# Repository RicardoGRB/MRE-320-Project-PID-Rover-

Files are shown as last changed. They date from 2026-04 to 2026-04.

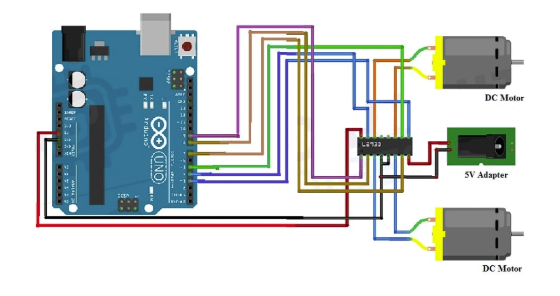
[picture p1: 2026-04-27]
Diagrams and Pictures/Wiring Diagrams/L293D&Motors_Diagram.png

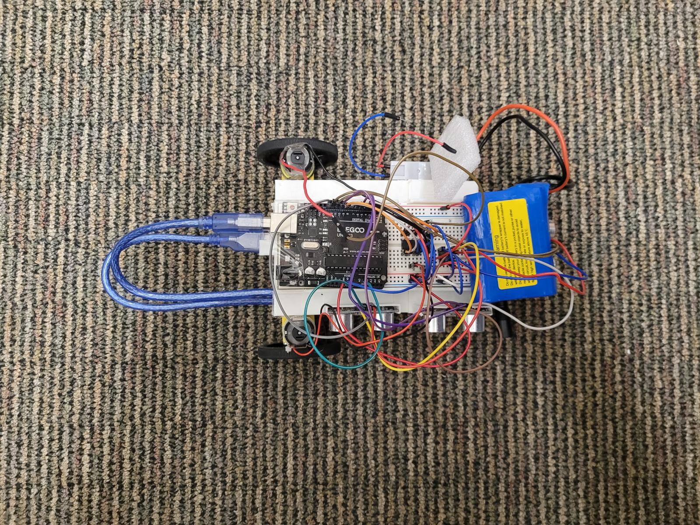
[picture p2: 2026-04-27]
Diagrams and Pictures/pictures/Rover above picture.jpeg

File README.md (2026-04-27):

# MRE-320-Project-PID-Rover-
# Autonomous Wall-Following Rover

## Overview

This project involves the design and implementation of an **autonomous mobile robot** capable of following a wall at a fixed distance using **feedback control**. The system uses ultrasonic sensors to measure distance and a **PID (Proportional–Integral–Derivative) controller** to continuously adjust the robot’s motion.

The project emphasizes the practical application of:

- Control systems (PID control)
- Sensor integration
- Embedded system design
- Mechanical design (custom chassis)

The rover was designed, built, and programmed to operate **fully autonomously**, maintaining a consistent distance from a wall while navigating alongside it.

---

## Project Goals

The main objectives of this project were:

- Design and build a **mobile robotic platform**
- Implement a **closed-loop control system** using a PID controller
- Maintain a **constant distance from a wall**
- Use **ultrasonic sensors** for real-time distance measurement
- Integrate hardware and software into a **fully autonomous system**
- Design and fabricate a **custom chassis** for the rover

---

## System Architecture

The rover system is composed of three main subsystems:

### 1. Sensing System

- Two **ultrasonic sensors** are mounted on the rover
- Sensors measure the **distance to the wall**
- Multiple sensors improve **stability and accuracy** of distance estimation

---

### 2. Control System

- A **PID controller** is implemented in the microcontroller
- The controller computes the error between:

  ```
  Error = Desired Distance − Measured Distance
  ```

- Based on this error, the controller adjusts motor behavior using:

  - **Proportional term (P):** reacts to current error  
  - **Integral term (I):** corrects accumulated error  
  - **Derivative term (D):** anticipates future error  

- The output of the PID controller is used to **adjust motor speeds** for steering correction

---

### 3. Actuation System

- The rover uses **two driven wheels** for propulsion
- A **passive omniwheel** is mounted at the front of the chassis
- The omniwheel allows **free lateral movement**, reducing friction during turns
- Steering is achieved through **differential drive**:
  - The robot turns by varying the speeds of the left and right motors
- This configuration enables **smooth directional corrections** while maintaining forward motion

---

### 4. Mechanical System

- A **custom chassis** was designed and built for the rover
- The chassis supports:
  - Sensor placement
  - Motor mounting
  - Electronics integration
  - Omniwheel placement for stability and maneuverability
- The design ensures:
  - Stability
  - Proper alignment with the wall
  - Reliable sensor readings

---

## Implementation Overview

### Sensor Integration

- Two ultrasonic sensors continuously measure the distance to the wall
- Sensor readings are processed in real time
- Data is used as input for the control algorithm

---

### Control Algorithm

1. Read distance from ultrasonic sensors  
2. Compute error relative to desired distance  
3. Apply PID control equation  
4. Generate correction signal  
5. Adjust motor speeds accordingly  

This loop runs continuously to ensure real-time response.

---

### Motor Control

- Motor speeds are adjusted based on PID output
- Differential drive is used to steer the rover
- The front omniwheel allows smooth turning without resistance
- Small speed adjustments result in precise wall-following behavior

---

### Chassis Design

- The rover chassis was **custom designed and built**
- Key considerations included:
  - Sensor positioning for accurate readings
  - Weight distribution
  - Structural stability
  - Integration of the omniwheel for improved maneuverability

---

## System Behavior

During operation, the rover:

1. Moves forward along a wall  
2. Continuously measures distance using ultrasonic sensors  
3. Computes error relative to the desired distance  
4. Adjusts its trajectory using PID control  
5. Maintains a stable and consistent path along the wall  

---

## Repository Structure

```
Autonomous-Wall-Following-Rover
│
├── README.md
│
├── code
│   └── rover_control
│
├── diagrams and Pictures
│   ├── chassis/solidworks
│   └── wiring_diagrams
│   └──pictures
│
├── data
│
├── engineering problem solving
│
└── final results

```

---

## Project Context

This project was completed as part of a **sensors and actuators assignment**, focusing on the integration of:

- Sensors  
- Control algorithms  
- Embedded programming  
- Mechanical design  

The project demonstrates a complete **mechatronic system**, combining hardware and software to achieve autonomous behavior.

---

---

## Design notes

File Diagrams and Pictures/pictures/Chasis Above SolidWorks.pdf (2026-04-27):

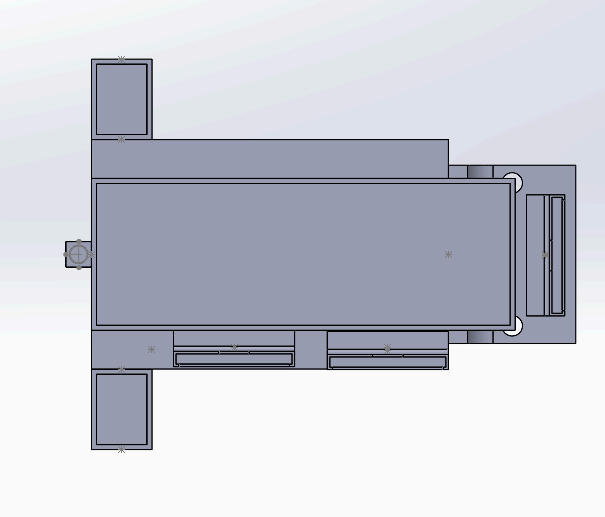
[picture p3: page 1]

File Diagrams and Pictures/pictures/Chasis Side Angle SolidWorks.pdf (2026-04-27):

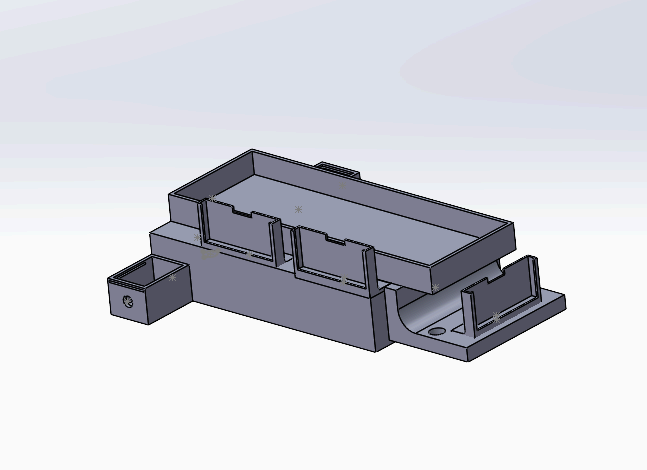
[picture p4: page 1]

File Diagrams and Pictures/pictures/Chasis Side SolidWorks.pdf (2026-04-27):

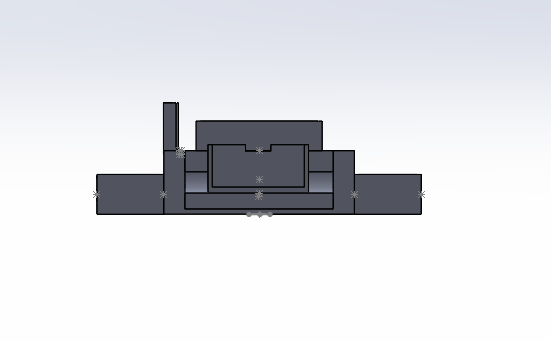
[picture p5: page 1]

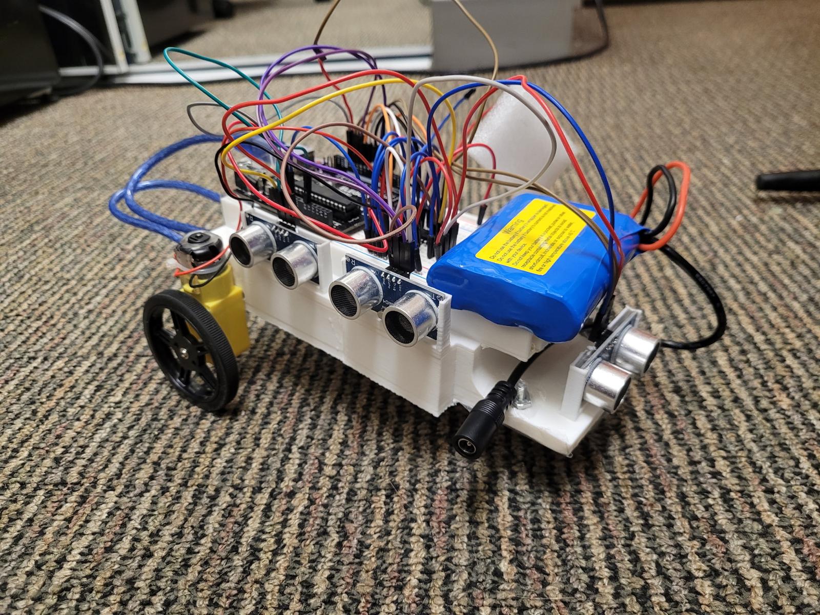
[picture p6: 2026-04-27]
Diagrams and Pictures/pictures/Rover side picture.jpeg

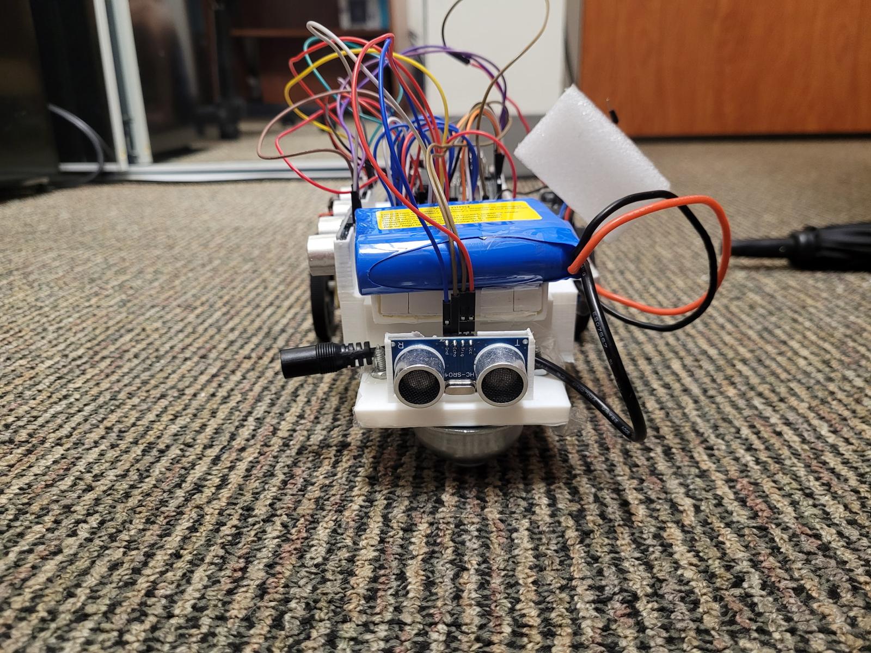
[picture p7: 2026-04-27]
Diagrams and Pictures/pictures/Rover Front picture.jpeg

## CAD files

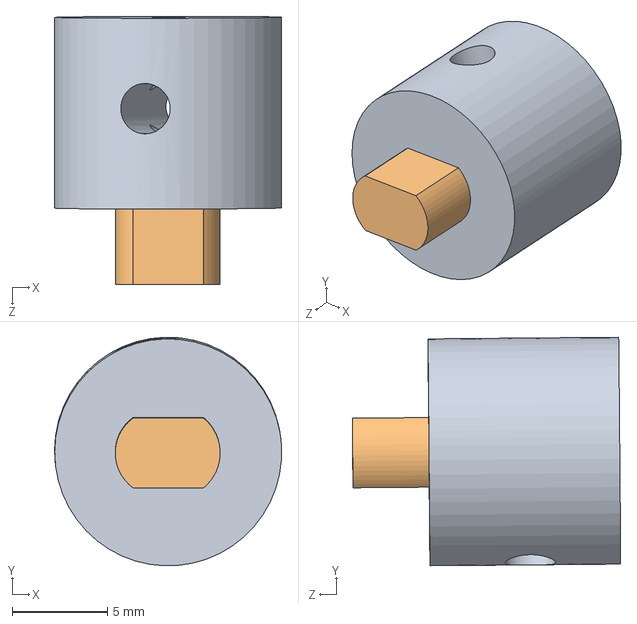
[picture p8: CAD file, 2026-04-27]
Diagrams and Pictures/Chasis/SolidWorksFiles/Motor assembly.SLDASM
11.9 x 12.0 x 14.1 mm
wheel hole
motor sheathe

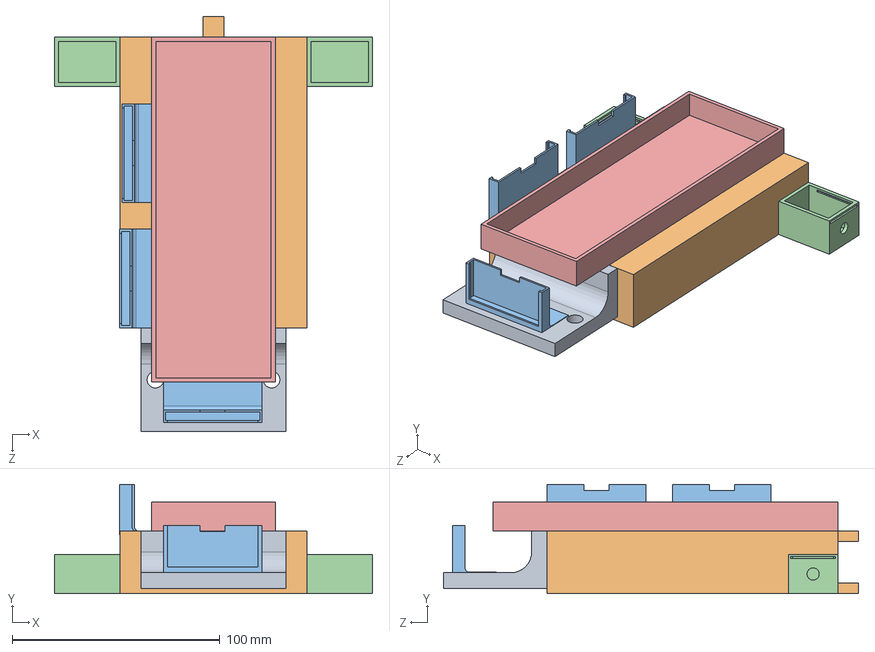
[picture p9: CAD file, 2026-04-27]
Diagrams and Pictures/Chasis/SolidWorksFiles/Final assembly.SLDASM
153.2 x 52.6 x 200.0 mm
bread board holder
motor box x 2
ultrasonic sensor plate x 3
Battery Case
RollerWheelMount

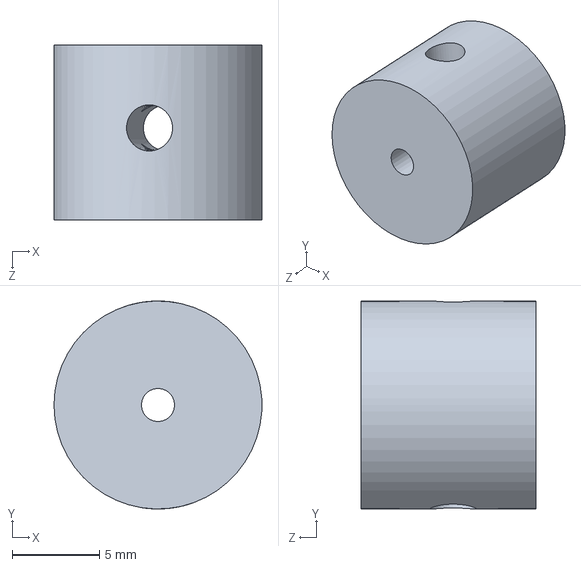
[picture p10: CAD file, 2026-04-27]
Diagrams and Pictures/Chasis/SolidWorksFiles/motor sheathe.SLDPRT
11.9 x 11.9 x 10.0 mm

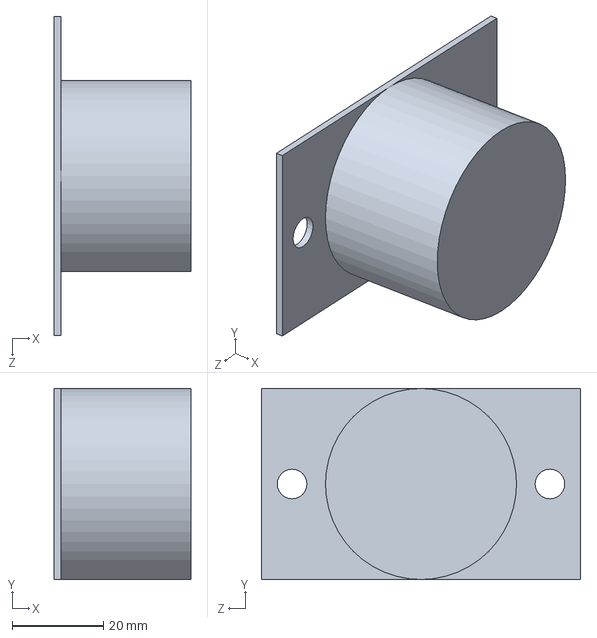
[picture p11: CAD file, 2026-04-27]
Diagrams and Pictures/Chasis/SolidWorksFiles/Front Wheel.SLDPRT
30.0 x 41.9 x 70.0 mm

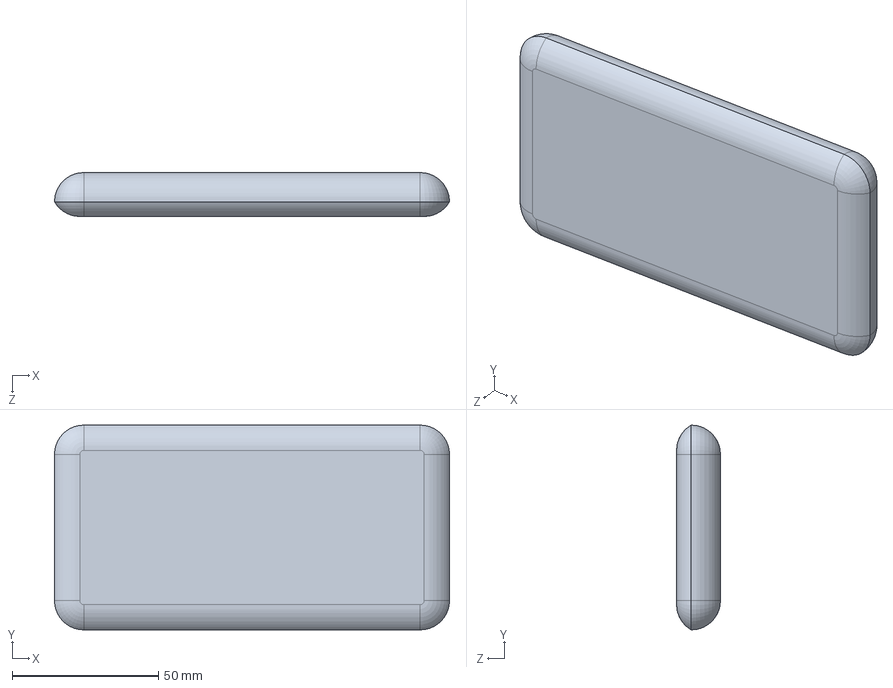
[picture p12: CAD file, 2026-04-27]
Diagrams and Pictures/Chasis/SolidWorksFiles/Battery.SLDPRT
135.0 x 70.0 x 15.0 mm

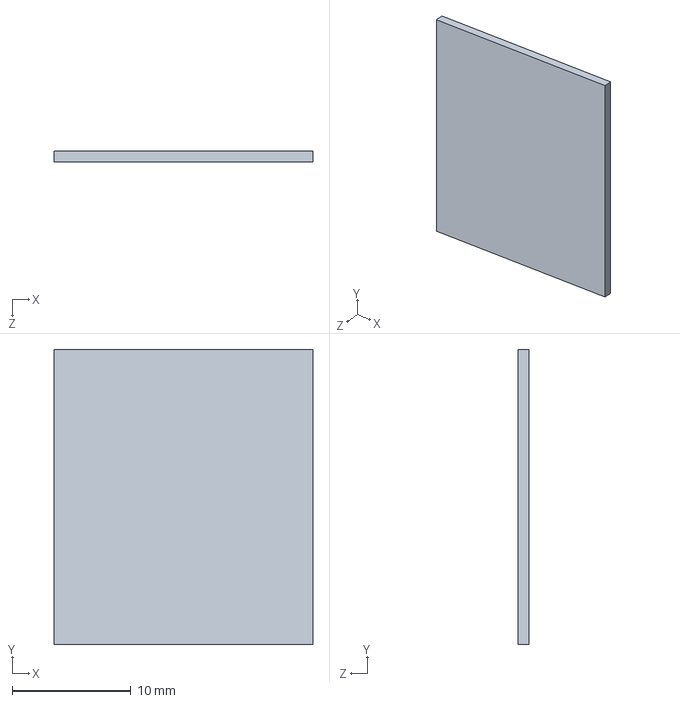
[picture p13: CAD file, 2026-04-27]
Diagrams and Pictures/Chasis/SolidWorksFiles/Motor box door.SLDPRT
21.7 x 24.8 x 0.95 mm

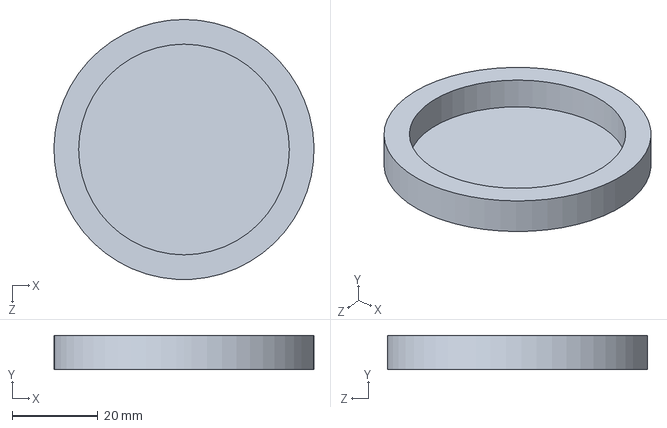
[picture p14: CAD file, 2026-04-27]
Diagrams and Pictures/Chasis/SolidWorksFiles/Rear Wheel.SLDPRT
60.5 x 8.00 x 60.5 mm

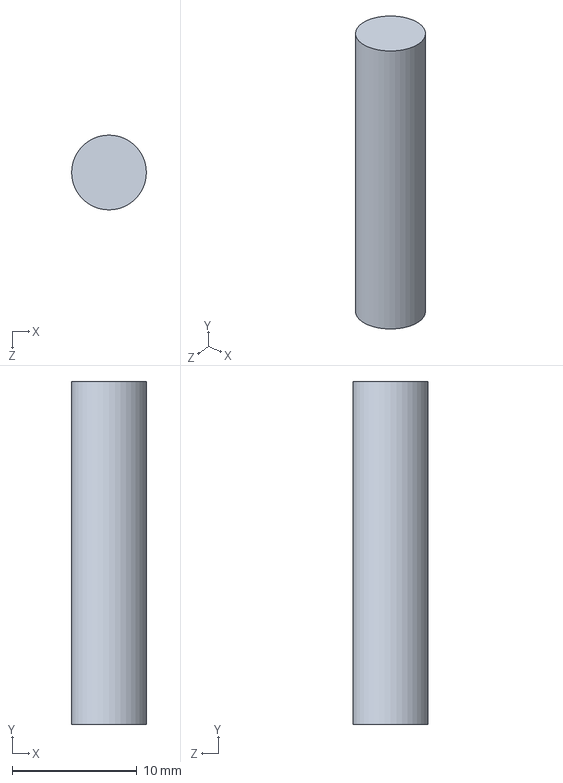
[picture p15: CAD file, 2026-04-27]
Diagrams and Pictures/Chasis/SolidWorksFiles/LockRod for Battery Case.SLDPRT
6.00 x 27.5 x 6.00 mm

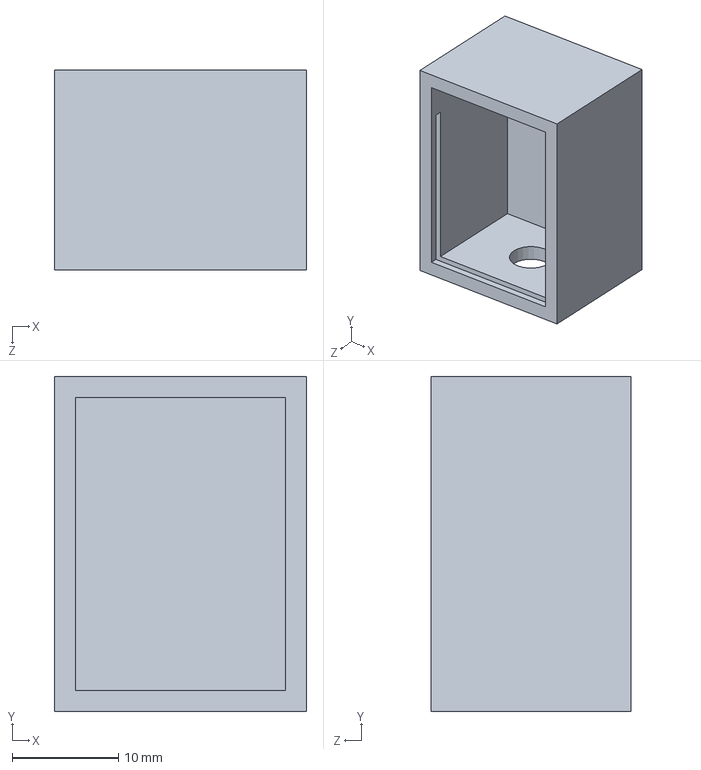
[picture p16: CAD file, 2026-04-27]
Diagrams and Pictures/Chasis/SolidWorksFiles/motor box.SLDPRT
23.8 x 31.6 x 18.9 mm

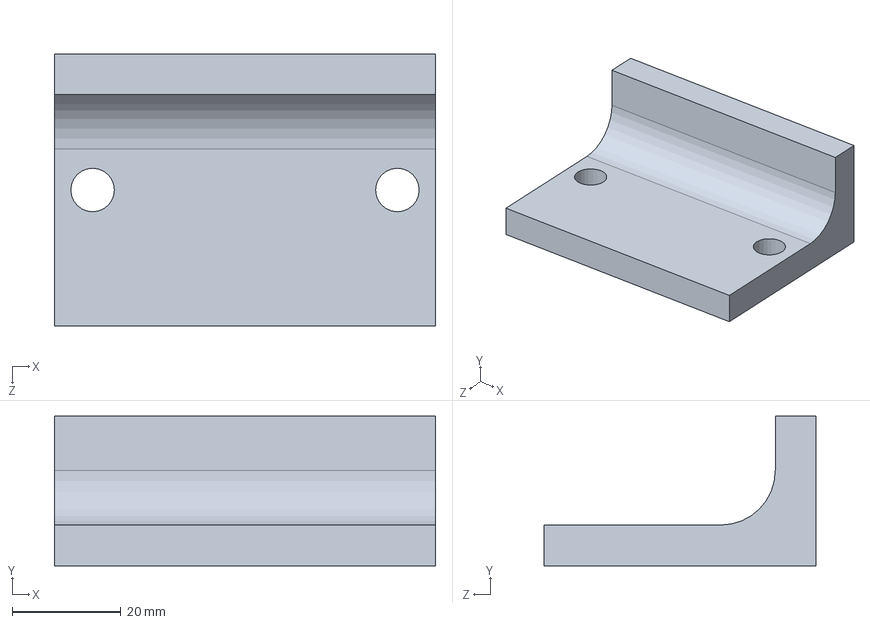
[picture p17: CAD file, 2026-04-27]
Diagrams and Pictures/Chasis/SolidWorksFiles/RollerWheelMount.SLDPRT
70.0 x 27.5 x 50.0 mm

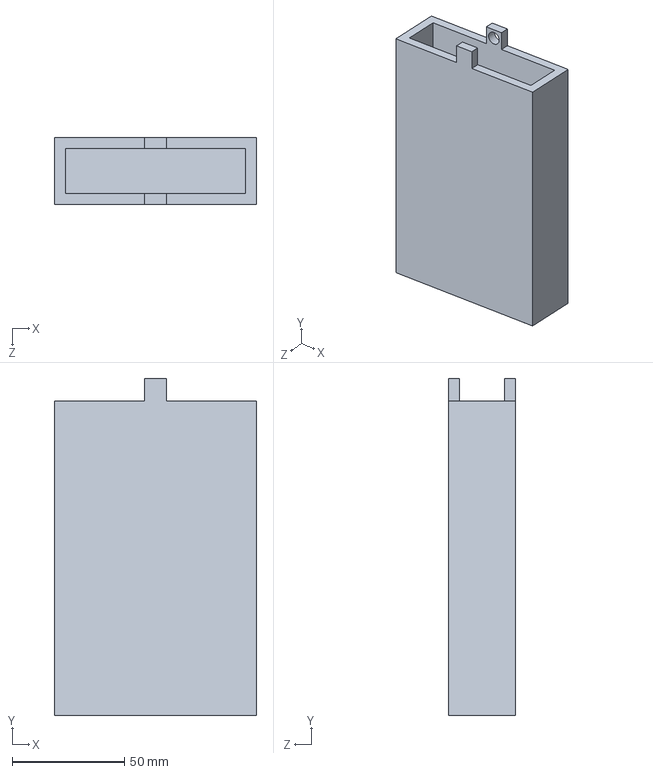
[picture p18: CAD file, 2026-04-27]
Diagrams and Pictures/Chasis/SolidWorksFiles/Battery Case.SLDPRT
90.0 x 150.0 x 30.0 mm

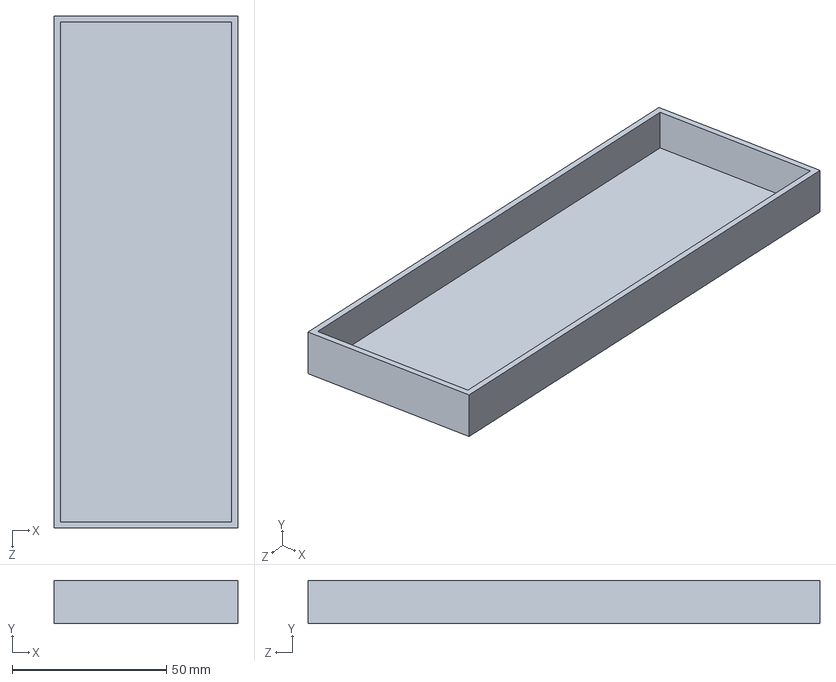
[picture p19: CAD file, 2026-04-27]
Diagrams and Pictures/Chasis/SolidWorksFiles/bread board holder.SLDPRT
59.6 x 14.0 x 166.2 mm

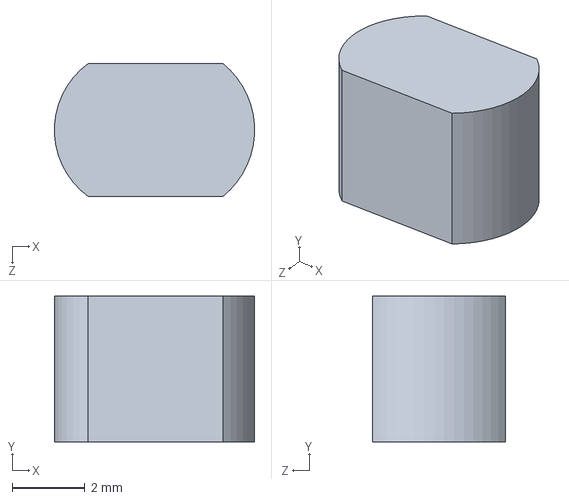
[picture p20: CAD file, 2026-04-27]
Diagrams and Pictures/Chasis/SolidWorksFiles/wheel hole.SLDPRT
5.49 x 4.00 x 3.65 mm

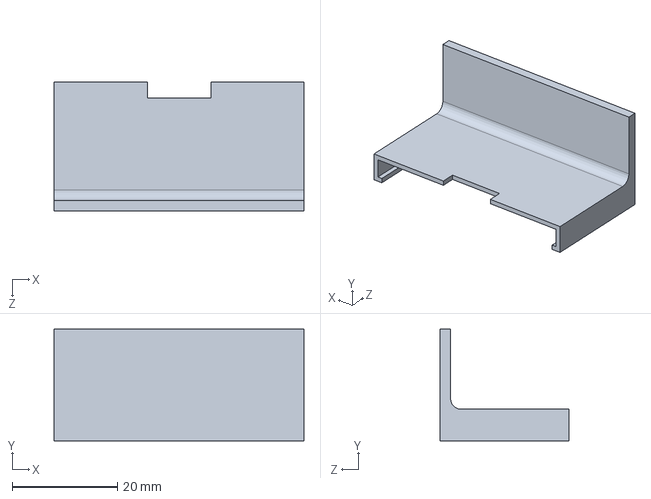
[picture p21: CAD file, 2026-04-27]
Diagrams and Pictures/Chasis/SolidWorksFiles/ultrasonic sensor plate.SLDPRT
47.5 x 21.2 x 24.5 mm

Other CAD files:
Diagrams and Pictures/Chasis/SolidWorksFiles/ultrasonic sensor mount.SLDPRT

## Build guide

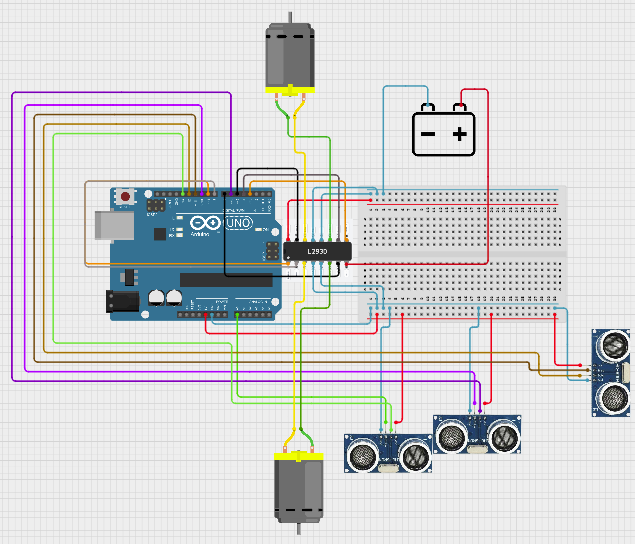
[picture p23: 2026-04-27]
Diagrams and Pictures/Wiring Diagrams/Master_Wiring_Diagram.png

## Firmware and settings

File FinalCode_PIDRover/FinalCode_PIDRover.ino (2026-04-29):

// ── Motor A (RIGHT WHEEL) ────────────────────────────────
const int ENA = 9;  const int IN1 = 8;  const int IN2 = 7;
// ── Motor B (LEFT WHEEL) ─────────────────────────────────
const int ENB = 3;  const int IN3 = 5;  const int IN4 = 4;
// ── Ultrasonic Sensors ───────────────────────────────────
const int TRIG_FRONT = 11; const int ECHO_FRONT = 12;
const int TRIG_SF    = 6;  const int ECHO_SF    = 10;  // Side-Front
const int TRIG_SR    = 13; const int ECHO_SR    = A0;  // Side-Rear

// ── Core Parameters ──────────────────────────────────────
const float TARGET_DIST     = 32.0;  // cm from wall
const float FRONT_STOP_DIST = 35.0;  // cm — stop threshold
const int   BASE_SPEED      = 90;    // 0–255 PWM base
const int   MAX_ADJUST      = 80;    // Max PID correction added/removed

// ── Motor Trim ───────────────────────────────────────────
// Boosting the weak left motor
const int LEFT_TRIM = 28;

// ── PID Gains ────────────────────────────────────────────
const float Kp = 1.5;
const float Ki = 0.05;
const float Kd = 2.5;

// ── Sensor Median Filter ─────────────────────────────────
const int FILTER_SIZE = 5;
long frontBuf[FILTER_SIZE], sfBuf[FILTER_SIZE], srBuf[FILTER_SIZE];
int  frontIdx = 0, sfIdx = 0, srIdx = 0;
bool frontFull = false, sfFull = false, srFull = false;

// ── PID State ────────────────────────────────────────────
float integral   = 0.0;
float lastError  = 0.0;
unsigned long lastTime = 0;

// ── Startup kick (one-time only) ─────────────────────────
bool started = false;

void setup() {
  pinMode(ENA, OUTPUT); pinMode(IN1, OUTPUT); pinMode(IN2, OUTPUT);
  pinMode(ENB, OUTPUT); pinMode(IN3, OUTPUT); pinMode(IN4, OUTPUT);
  pinMode(TRIG_FRONT, OUTPUT); pinMode(ECHO_FRONT, INPUT);
  pinMode(TRIG_SF,    OUTPUT); pinMode(ECHO_SF,    INPUT);
  pinMode(TRIG_SR,    OUTPUT); pinMode(ECHO_SR,    INPUT);

  for (int i = 0; i < FILTER_SIZE; i++) {
    frontBuf[i] = 100;
    sfBuf[i]    = TARGET_DIST;
    srBuf[i]    = TARGET_DIST;
  }

  Serial.begin(9600);
  Serial.println("PID Wall Follower Ready");
  Serial.print("LEFT_TRIM = "); Serial.println(LEFT_TRIM);
}

// ── Raw distance read. Returns -1 on timeout/invalid. ────
long readRaw(int trigPin, int echoPin) {
  digitalWrite(trigPin, LOW);
  delayMicroseconds(2);
  digitalWrite(trigPin, HIGH);
  delayMicroseconds(10);
  digitalWrite(trigPin, LOW);

  long duration = pulseIn(echoPin, HIGH, 25000);
  if (duration <= 0) return -1;
  long dist = duration * 0.034 / 2;
  if (dist < 1 || dist > 400) return -1;
  return dist;
}

// ── Push a valid reading into a circular buffer. ─────────
void pushReading(long val, long* buf, int &idx, bool &full) {
  if (val == -1) return;
  buf[idx] = val;
  idx = (idx + 1) % FILTER_SIZE;
  if (idx == 0) full = true;
}

// ── Compute median of a buffer. ──────────────────────────
long median(long* buf, bool full) {
  int n = full ? FILTER_SIZE : 1;
  long sorted[FILTER_SIZE];
  memcpy(sorted, buf, n * sizeof(long));
  for (int i = 1; i < n; i++) {
    long key = sorted[i];
    int j = i - 1;
    while (j >= 0 && sorted[j] > key) { sorted[j+1] = sorted[j]; j--; }
    sorted[j+1] = key;
  }
  return sorted[n / 2];
}

// ── Drive both motors forward. LEFT_TRIM applied here. ───
void setMotors(int leftSpeed, int rightSpeed) {
  // Boost the weaker left motor
  leftSpeed = leftSpeed + LEFT_TRIM;

  leftSpeed  = constrain(leftSpeed,  0, 255);
  rightSpeed = constrain(rightSpeed, 0, 255);

  digitalWrite(IN3, HIGH); digitalWrite(IN4, LOW);  // Left forward
  digitalWrite(IN1, HIGH); digitalWrite(IN2, LOW);  // Right forward
  analogWrite(ENB, leftSpeed);
  analogWrite(ENA, rightSpeed);
}

void stopMotors() {
  analogWrite(ENA, 0);
  analogWrite(ENB, 0);
  integral  = 0.0;
  lastError = 0.0;
  started   = false;
}

void loop() {
  // 1. Read sensors into buffers
  pushReading(readRaw(TRIG_FRONT, ECHO_FRONT), frontBuf, frontIdx, frontFull);
  delay(5);
  pushReading(readRaw(TRIG_SF, ECHO_SF),       sfBuf,    sfIdx,    sfFull);
  delay(5);
  pushReading(readRaw(TRIG_SR, ECHO_SR),       srBuf,    srIdx,    srFull);

  // 2. Get filtered distances
  long frontDist = median(frontBuf, frontFull);
  long sfDist    = median(sfBuf,    sfFull);
  long srDist    = median(srBuf,    srFull);

  Serial.print("F:"); Serial.print(frontDist);
  Serial.print(" SF:"); Serial.print(sfDist);
  Serial.print(" SR:"); Serial.println(srDist);

  // 3. Front obstacle check
  if (frontDist < FRONT_STOP_DIST) {
    stopMotors();
    Serial.println(">>> STOPPED: Front obstacle <<<");
    delay(200);
    return;
  }

  // 4. One-time startup kick to overcome static friction
  if (!started) {
    digitalWrite(IN3, HIGH); digitalWrite(IN4, LOW);
    digitalWrite(IN1, HIGH); digitalWrite(IN2, LOW);
    analogWrite(ENB, constrain(255 + LEFT_TRIM, 0, 255)); // Left kick with trim
    analogWrite(ENA, 255);                                 // Right kick
    delay(300);
    started = true;
    lastTime = millis();
  }

  // 5. Compute dt
  unsigned long now = millis();
  float dt = (now - lastTime) / 1000.0;
  if (dt <= 0) dt = 0.04;
  lastTime = now;

  // ── PID CONTROL ──────────────────────────────────────────
  float sideDist   = (sfDist + srDist) / 2.0;
  float distError  = sideDist - TARGET_DIST;
  float angleError = (float)(sfDist - srDist);
  float error      = distError + (angleError * 0.6);

  // P term
  float P = Kp * error;

  // I term (with windup clamp)
  integral += error * dt;
  integral = constrain(integral, -50.0, 50.0);
  float I = Ki * integral;

  // D term
  float D = Kd * ((error - lastError) / dt);
  lastError = error;

  float correction = P + I + D;
  correction = constrain(correction, -MAX_ADJUST, MAX_ADJUST);

  // Positive error = too far from wall → steer right → left faster, right slower
  int leftSpeed  = BASE_SPEED + (int)correction;
  int rightSpeed = BASE_SPEED - (int)correction;

  setMotors(leftSpeed, rightSpeed);

  Serial.print("err:"); Serial.print(error);
  Serial.print(" P:"); Serial.print(P);
  Serial.print(" I:"); Serial.print(I);
  Serial.print(" D:"); Serial.print(D);
  Serial.print(" L:"); Serial.print(leftSpeed + LEFT_TRIM); // Show actual PWM
  Serial.print(" R:"); Serial.println(rightSpeed);

  delay(40);
}

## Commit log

2026-04-27 Create Wiring Diagrams
2026-04-27 Create Ultrasonic Sensor
2026-04-27 Create Ultrasonic Sensor
2026-04-27 Create • Measured data and analysis
2026-04-27 Rename • Measured data and analysis to Measured data and analysis
2026-04-27 Update and rename • Engineering problem-solving reflection to Engineering problem-solving reflection
2026-04-30 Create PID Analysis and Tuning
2026-04-30 Update PID Analysis and Tuning
